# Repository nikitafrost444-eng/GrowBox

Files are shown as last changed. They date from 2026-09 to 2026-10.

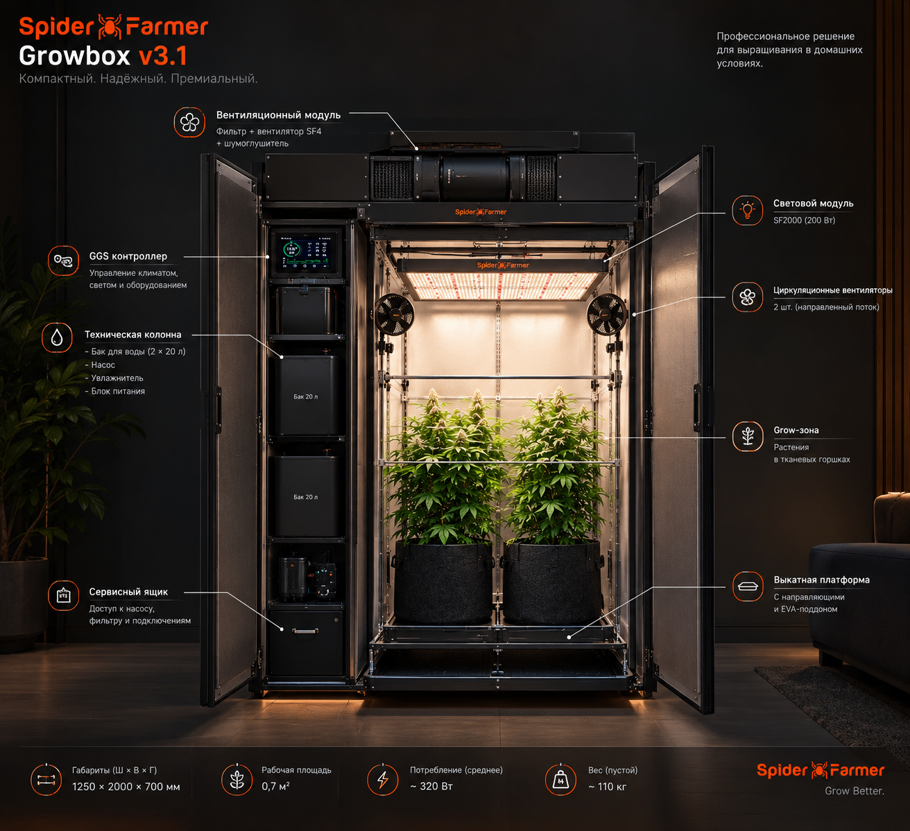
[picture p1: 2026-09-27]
images/concepts/ai_01_21-43.png

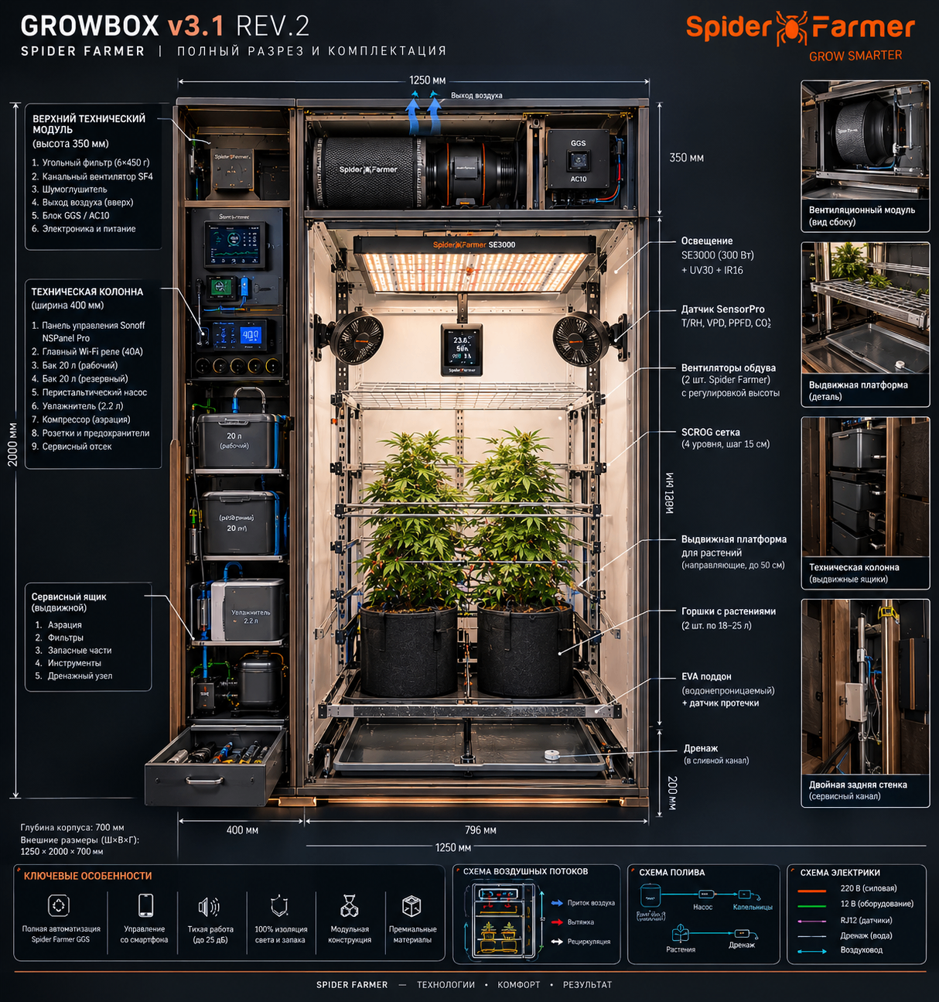
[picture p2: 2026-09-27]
images/concepts/ai_05_uuid.png

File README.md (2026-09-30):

# GrowBox — премиальный гроушкаф (проект v3.0 / v3.1 rev.2)

Тихий шкаф-гроубокс на 2 растения (SCROG) с полной автоматикой Spider Farmer GGS.
Принцип проекта: *выглядит как мебель · звучит как тишина · работает как швейцарские часы*.

**Габариты:** 1250 × 700 × 2000 мм · **Зона растений:** 796 × 620 мм (~0,49 м²) · **Свет:** SE3000 (300 Вт) на актуаторе · **Тишина:** вентиляция Ø100 с шумоглушителем и виброподвесами

---

## 🗂 Структура репозитория

| Папка | Содержимое |
|---|---|
| `docs/` | Документация: полное описание v1.0, спецификация v3.0 с картой раскроя, **v3.1 акустический техмодуль и шумоглушитель**, крепёжная карта, журналы сессий |
| `docs/drawings/` | Инженерные чертежи: разрез и план верхнего акустического модуля v3.1 |
| `models/` | 3D-модель: STEP (для КОМПАС-3D), STL, GLB + веб-просмотрщик, исходники (CadQuery) |
| `models/v3.1/` | **CAD v3.1 rev.2 (модульная архитектура A/B/C):** STEP по каждой детали + полная сборка, DXF раскроя, карта раскроя CSV, протокол проверок, исходник CadQuery |
| `models/renders/` | Цветные рендеры: общий вид, фасад, бок, разрез, сверху |
| `models/previews/` | Чертёжные SVG-превью |
| `pdf/` | Издательские PDF: концепция v1.0, описание v2.0, сборки v3.0 и v3.1 rev.2, **v3.1 rev.3 — полное описание и инструкция по сборке** |
| `images/concepts/` | AI-концепты внешнего вида |
| `images/equipment/` | Фото оборудования (SE3000, AC10, вентиляция, датчики и т.д.) |
| `sources/chats/` | Исходные обсуждения (Qwen, Алиса, ChatGPT) — стратегия, железо, модули |
| `sources/pdf-build/` | Вёрстка итогового PDF (HTML-страницы) и QA-скриншоты |

## 📄 С чего начать

1. **Спецификация и размеры** → [`docs/growbox_v3_spec.md`](docs/growbox_v3_spec.md) — канон v3.0: габариты, зонирование, электрика (2× AC10, 20 каналов), воздушный тракт, карта раскроя ЛДСП.
2. **Полное описание проекта** → [`docs/proekt_v1.0.txt`](docs/proekt_v1.0.txt) — исследование сообществ, акустика, вентиляция, автополив, спецификация Spider Farmer GGS.
3. **3D-модель** → `models/growbox_v3.step` — открыть в КОМПАС-3D (Файл → Открыть/Импорт), 76 именованных деталей; либо `models/viewer.html` + `models/growbox_v3.glb` в браузере.
4. **Итоговый PDF** → `pdf/growbox_v31_rev2.pdf`.
5. **v3.1 (в работе)** → [`docs/growbox_v3.1_acoustic-tech-module.md`](docs/growbox_v3.1_acoustic-tech-module.md) — верхний акустический техмодуль; [`docs/growbox_v3.1_silencer.md`](docs/growbox_v3.1_silencer.md) — самодельный двухкамерный шумоглушитель; [`docs/growbox_v3.1_fasteners.md`](docs/growbox_v3.1_fasteners.md) — крепёжная карта (узлы, крепёж, ссылки). Чертежи в `docs/drawings/`.
6. **CAD v3.1 rev.2 (модули A/B/C)** → [`models/v3.1/`](models/v3.1/) — 85 деталей, полная сборка STEP, DXF раскроя; импорт в КОМПАС-3D — по [`docs/kompas_import_v3.1.md`](docs/kompas_import_v3.1.md).
7. **📄 Главный документ rev.3** → [`pdf/growbox_v31_rev3.pdf`](pdf/growbox_v31_rev3.pdf) — полное описание, архитектура, инструкция по сборке и обслуживанию, чек-листы (12 страниц, цветные рендеры).

## 💻 Локальная сборка на своём ПК (Windows)

Чтобы не скачивать готовые файлы, а пересобирать модель под свои размеры:

1. Установи [Python 3.12](https://python.org/downloads/) — **с галочкой «Add python.exe to PATH»**
2. Склонируй репозиторий (или скачай ZIP: кнопка `Code → Download ZIP`)
3. В папке проекта запусти `setup.ps1` (правой кнопкой → Run with PowerShell) — поставит CadQuery
4. Запусти `build.bat` — модель пересоберётся, файлы обновятся в `models/v3.1/`

Чтобы поменять размеры: открой `models/v3.1/build_v31_modular.py`, блок параметров `P = dict(...)`
в начале (ширины модулей, толщины ЛДСП, габариты оборудования) → сохрани → `build.bat`.
Протокол проверок габаритов — `models/v3.1/reports/fit_check.txt`.

## 🔧 Ключевые решения v3.0

- **Свет:** SE3000 (603×585×71, PPF 856) — встаёт в зону с зазорами 96 мм по бокам; SE4500 снят (не влезает). Дополнительно UV30/IR16, зелёная подсветка 520–540 нм, актуатор подъёма 12 В (ход 300 мм).
- **Вентиляция:** лабиринт-приток → угольный фильтр SF 4" → вентилятор SF 4" (виброподвесы) → шумоглушитель → решётка 400×300 в комнату. Рабочие 80–135 м³/ч при объёме зоны 0,97 м³, разрежение обязательно.
- **Автоматика:** GGS Controller + 2× AC10 (20 розеток), ESP32, автодозатор A/B/микро + pH-модуль, перистальтика, компрессор аэрации, ИБП 600 ВА, Wi-Fi камера, датчик протечки, Soil Sensor Pro.
- **Корпус:** ЛДСП 18 мм, мокрая зона — фанера 18 + моющееся покрытие; раскладка по ширине 18+400+18+796+18 = 1250 мм. Раскрой укладывается в 2 листа 2800×2070.

## 🛠 Пересборка модели

Модель параметрическая (CadQuery):
```bash
python models/build_growbox_v3.py     # сборка STEP/STL/GLB
python models/render_matplotlib.py    # цветные рендеры
```

## 📌 Примечания

- `docs/opisanie_v2.0_broken-encoding.txt` — историческая выгрузка PDF v2.0 с битой кодировкой кириллицы (сохранена как есть; рабочая версия — `docs/proekt_v1.0.txt` и спецификация v3.0).
- `docs/session-notes_2026-09-27.md` — журнал принятых решений и технические заметки сессии проектирования.
- Открытые вопросы: летний сценарий (сплит в спальне?), конкретная модель Wi-Fi камеры.

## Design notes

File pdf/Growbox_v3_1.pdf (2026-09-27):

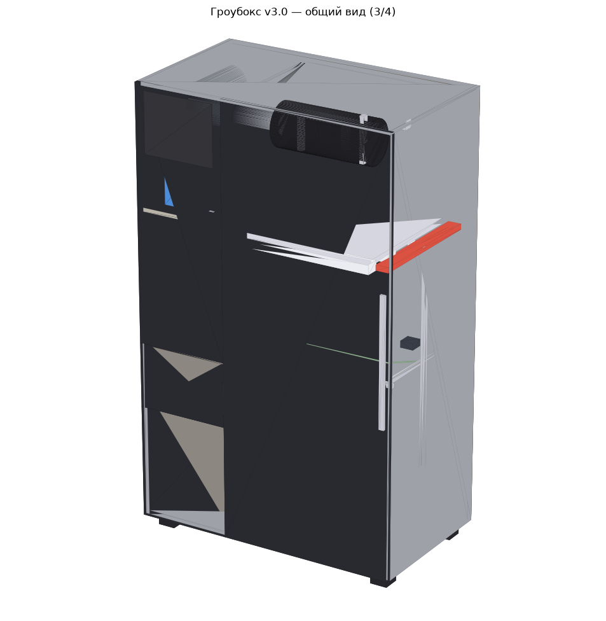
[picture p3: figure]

GROWBOX v3.1 • Spider Farmer centered concept | 1

# GROWBOX v3.1

## Spider Farmer centered • концепт инженерной ревизии

Цель версии: сохранить сильную механику v3.0, но сделать GGS единым центром климатической автоматизации, сократить самописную автоматику и повысить сервисопригодность, тишину и безопасность.

Ключевая идея: Spider Farmer управляет средой; корпус, разводка и аварийная защита проектируются независимо.

Документ подготовлен 27.09.2026. Это проектная ревизия, а не инструкция по сборке электроустановки. Перед изготовлением необходимо отдельно проверить актуальные модели, совместимость разъёмов GGS/RJ12 и требования местных электрических норм.

# 1. Что меняется в v3.1

v3.0 уже имеет хорошую базу: 1250×700×2000 мм, отдельную техколонну, влажную зону, SE3000, SF4, два почвенных датчика, резервный бак и полноценную сервисную панель. Главная проблема — слишком много параллельных систем управления.

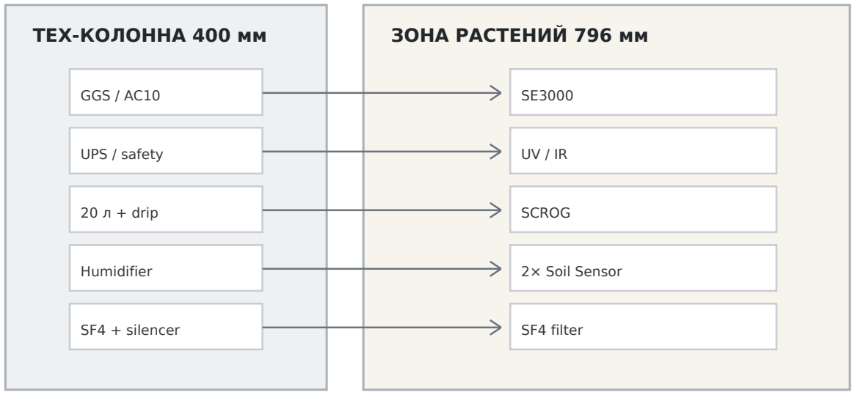
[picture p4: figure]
ТЕХ-КОЛОННА 400 мм; ЗОНА РАСТЕНИЙ 796 мм; GGS / AC10; UPS / safety; 20 л + drip; Humidifier; SF4 + silencer; SCROG; 2× Soil Sensor; SF4 filter

v3.1: GGS — главный мозг; механика и safety — независимые слои

## Решение v3.1

Узел | v3.0 | v3.1
Мозг | GGS + ESP32 | GGS как основной контроллер
Полив | собственная перистальтика + ESP32 | Spider Farmer Smart Drip / Soil Sensor
Свет | SE3000 + актуатор | SE3000, фиксированная механика, GGS/APP
Вентиляция | SF4 + AC10 | SF4 + GGS, плавное управление
pH / дозирование | самописный контур | отдельный сервисный контур
Safety | реле + ESP32 | независимый аварийный слой + leak shutdown

# 2. Корпус и компоновка

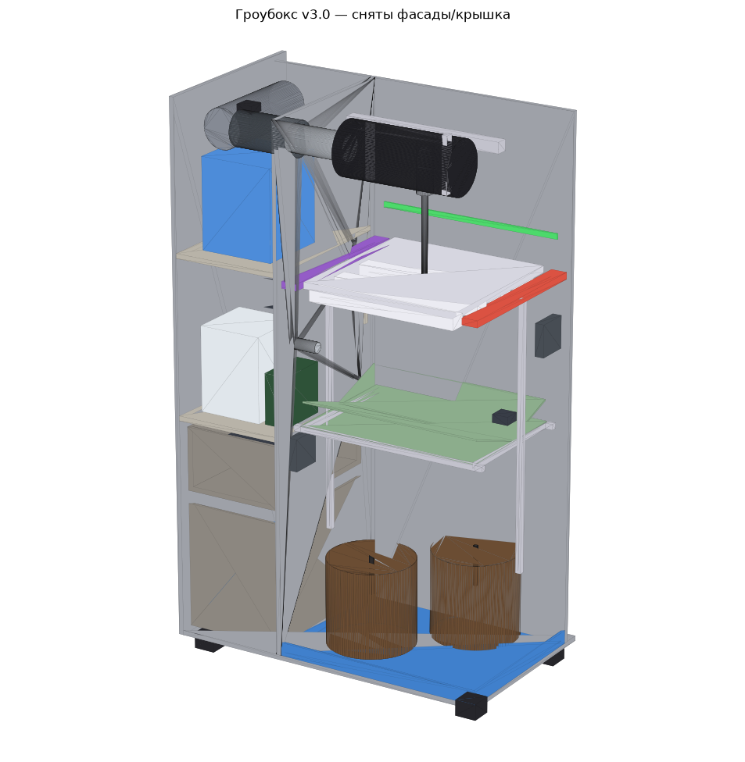
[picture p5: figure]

Канон v3.0: 1250 × 700 × 2000 мм; техколонна 400 мм; зона растений 796 × 620 × 1964 мм; задний кабельный колодец 58 мм.

Рекомендация v3.1: не фиксировать изготовление до финальной проверки BBox STEP. В исходной проектной документации отдельно отмечено расхождение между каноном и фактической габаритной геометрией модели. Для сервисной части предпочтителен увеличенный кабельный объём 80–100 мм, если помещение позволяет.

## Компоновка техколонны

Высота | Модуль v3.1 | Комментарий
0–520 | Рабочий бак 20 л | поддон + датчик протечки
520–820 | Полив / насос | съёмный сервисный ящик

820–1080 | Увлажнение / сервис | не ставить аэрозоль рядом с электроникой
1080–1420 | GGS / AC10 / БП | съёмная DIN-панель
1420–1778 | Резервный бак 20 л | механическая защита от перелива
1778–1982 | SF4 + шумоглушение | мягкий подвес

# 3. Свет — SE3000 как база

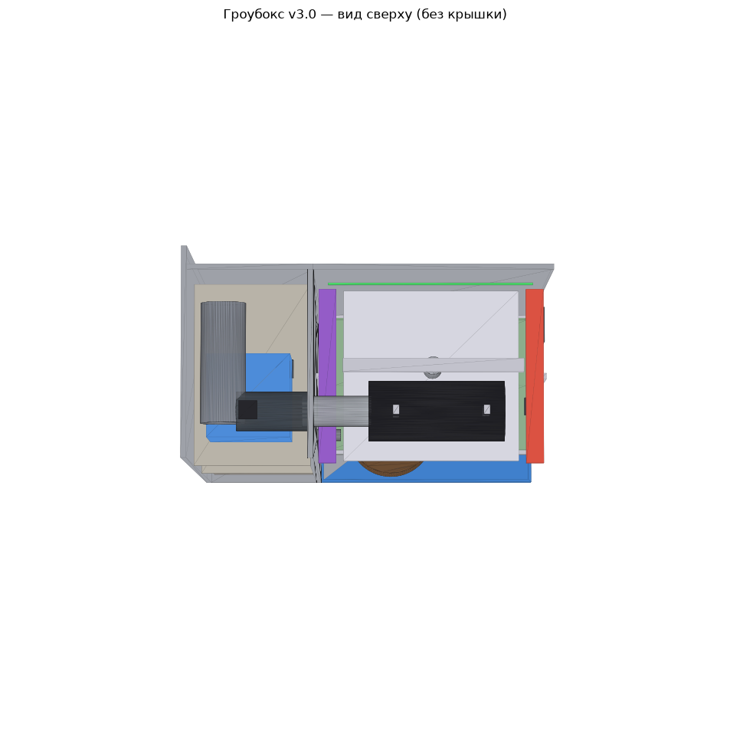
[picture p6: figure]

Актуальная страница Spider Farmer для 2026 SE3000 указывает 300 Вт, PPF 856 µmol/s, PPE 2.85 µmol/J, размеры около 603×585×71 мм и максимальное покрытие 3×3 ft. Новая версия использует Bridgelux; управление заявлено через Bluetooth/Wi‑Fi приложение и 0–10V. cite?

Для зоны 796×620 мм SE3000 подходит по геометрии и по площади. В v3.1 я бы убрал моторизированный подъём светильника: фиксированная механика + диммирование дают меньше движущихся деталей, меньше кабельных проблем и меньше точек отказа.

UV30 / IR16: оставить как отдельные вспомогательные каналы, но использовать их по расписанию, без сложной самописной логики.

Источник спецификаций: urlофициальная страница Spider Farmer SE3000https://www.spider-farmer.com/products/spider-farmer-upgraded-se3000-full-spectrum-led-grow-light/

# 4. Вентиляция и шум

Приток | Зона роста | Фильтр | SF4 | Шумоглушитель

Разрежение внутри зоны • фильтр строго ДО вентилятора • большой тихий выход

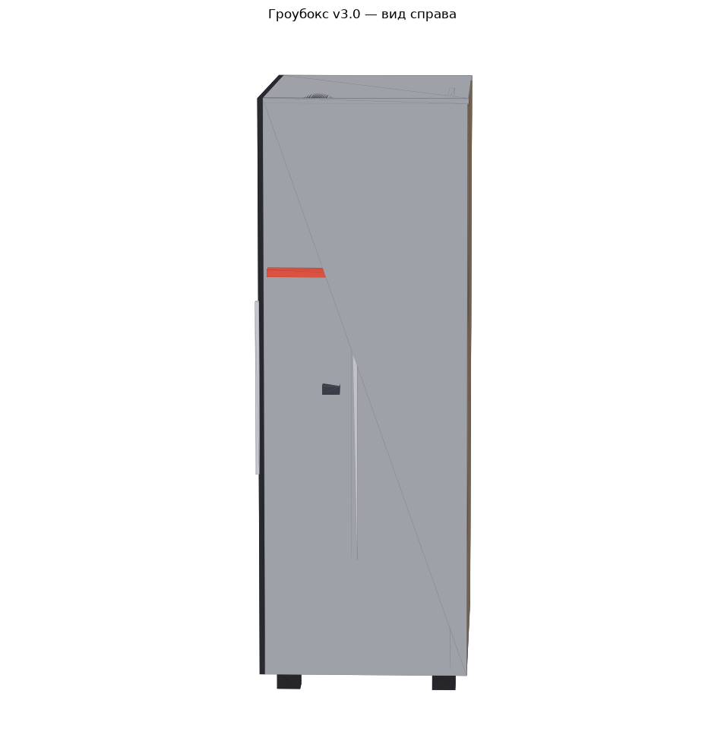
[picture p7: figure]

Схема v3.1: приток → зона растений → угольный фильтр → SF4 → шумоглушитель → большой выходной пленум. Фильтр остаётся до вентилятора, внутри шкафа поддерживается лёгкое разрежение.

Почему оставить SF4: текущая документация уже оптимизирована под компактный Ø100 тракт, а официальный Spider Farmer прямо указывает 4-inch fan как рекомендуемый для SE3000. Для этой камеры важнее хороший фильтр, плавная скорость и отсутствие резких сужений, чем максимальная производительность.

Шумоизоляция: вентилятор на виброразвязке; минимум 1–2 мягких участка; длинный тихий участок после вентилятора; выходной пленум с большой площадью решётки.

# 5. GGS — единый центр управления

Управляемые нагрузки

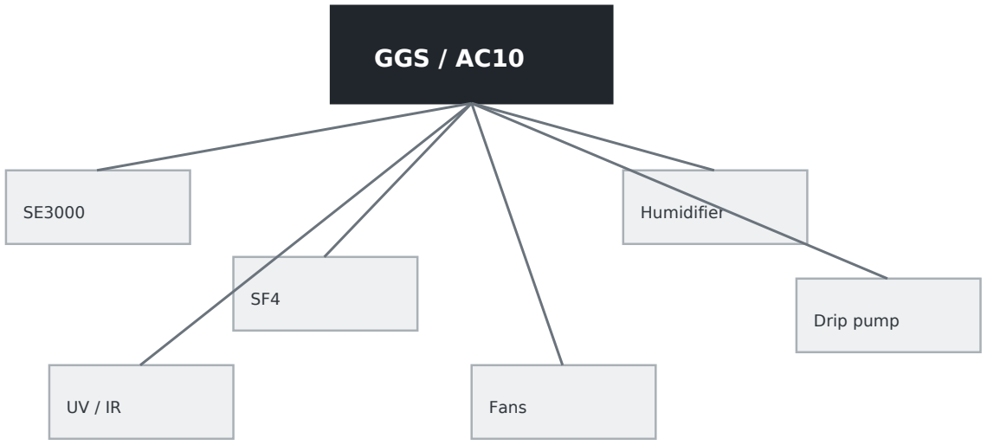
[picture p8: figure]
GGS / AC10; Humidifier; Drip pump; Fans

Spider Farmer сейчас предлагает связку GGS-контроллера с SE3000, 4-inch inline fan и климатическими датчиками; в официальных комплектах используются RJ12-соединения и управление через приложение. urlОфициальный комплект Spider Farmer с SE3000 + 4-inch fan + GGShttps://www.spider-farmer.com/products/spider-farmer-se3000-300w-led-grow-light-2x2x5%E2%80%B2-indoor-grow-tent-combo/

v3.1 принципиально меняет философию: ESP32 не управляет обычным режимом. Он либо удаляется, либо остаётся независимым монитором/аварийным слоем. Это снижает количество программных зависимостей и делает систему понятнее для обслуживания.

## Распределение каналов

Канал | Нагрузка | Логика
1 | SE3000 | расписание + диммирование
2 | SF4 | температура / RH / минимум ночью
3 | обдув | постоянно или по климату
4 | увлажнитель | по RH/VPD
5 | drip pump | Soil Sensor / расписание
6 | UV/IR | отдельное расписание
7+ | резерв | обогрев / сервис / будущее

# 6. Полив, датчики и вода

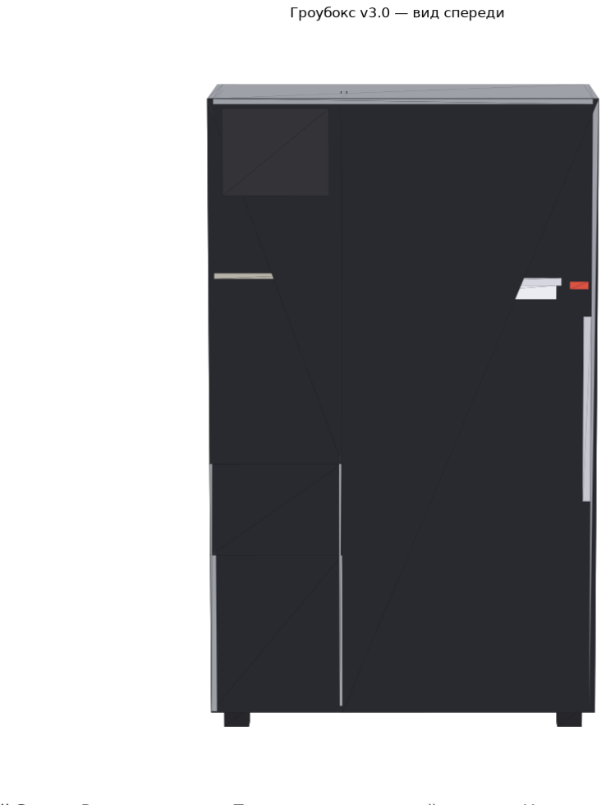
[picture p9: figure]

Два Soil Sensor Pro — оставить. По одному на каждый горшок. Не усреднять их показания: каждое растение получает собственную обратную связь.

Для v3.1 предпочтителен Spider Farmer Smart Drip/совместимый GGS-контур вместо самописной перистальтики, если конкретная версия системы доступна в твоём регионе и подтверждена совместимостью с выбранным AC10. Это наиболее прямой путь к цели «Spider Farmer ecosystem».

pH/EC: не смешивать с основной климатической логикой. Если нужен полностью автоматический pH dosing, это отдельный специализированный контур; GGS не следует превращать в самописный химический контроллер.

## Safety water layer

Событие | Немедленное действие
Протечка | насос OFF + увлажнитель OFF
Переполнение | подача OFF
Перегрев | SF4 → высокий режим

Потеря связи GGS | безопасный последний режим + независимый watchdog

# 7. Предварительная спецификация v3.1

Категория | Решение | Статус
Свет | Spider Farmer SE3000 300W (2026) | Оставить
UV/IR | Spider Farmer UV/IR bars | Оставить
Контроллер | Spider Farmer GGS | Главный мозг
Питание | AC10 / совместимый GGS power control | Уточнить финальную ёмкость каналов
Датчик климата | GGS Sensor / SensorPro | Оставить
Почва | 2× Soil Sensor Pro | Оставить
Вентиляция | Spider Farmer 4-inch inline fan | Оставить
Фильтр | Spider Farmer 4-inch carbon filter | Оставить
Обдув | Spider Farmer clip fan | Оставить
Увлажнение | Spider Farmer 5 L class humidifier | Оставить
Полив | Spider Farmer Smart Drip / GGS-compatible | Предпочтительно
pH/EC | отдельный сервисный контур | Опционально
ESP32 | монитор / safety only | Убрать из normal control
Актуатор света | моторизированный подъём | Убрать
Протечка | независимый hard shutdown | Добавить

# 8. Что проверить перед переходом к CAD

v3.1

① Зафиксировать внешний габарит и устранить расхождение STEP/BBox. ② Подтвердить конкретную ревизию AC10/GGS и количество доступных каналов. ③ Подтвердить совместимость выбранного SF4 с GGS/RJ12. ④ Проверить реальную геометрию фильтра и SF4 в верхнем отсеке. ⑤ Определить финальную схему полива и дренажа. ⑥ Разнести силовую и слаботочную трассы. ⑦ Сделать отдельную проверку теплового режима и аварийных сценариев.

Официальные источники: urlSpider Farmer — SE Serieshttps://www.spider-farmer.com/collections/led-grow-light/se-series-led-grow-light/ • urlSpider Farmer — GGS / комплектыhttps://www.spider-farmer.com/shop/ • urlSpider Farmer — центр руководствhttps://www.spider-farmer.com/user-manual-download-center/

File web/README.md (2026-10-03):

# Web · интерактивная 3D-модель GrowBox v3.1

Каноническая веб-страница с 3D-моделью шкафа. Геометрия **не нарисована на глаз** —
она сгенерирована из параметрической сборки `models/v3.1/build_v31_modular.py`
(те же 85 деталей, те же размеры, зазоры и петли).

## Файлы

| Файл | Что это |
|---|---|
| `index.html` | Основная страница: полный 3D, двери/ящики/газлифты, разрез, выбор деталей |
| `viewer_mobile.html` | Компактный просмотрщик под телефон (та же геометрия) |
| `model_parts.js` | Данные модели: 85 деталей (bbox, цвет, тип) из CAD |
| `vendor/three.min.js` | Three.js r128 (UMD, работает офлайн и с `file://`) |

## Как открыть

Просто открой `index.html` в браузере (двойной клик). Интернет не нужен —
библиотека и данные лежат рядом со страницей.

## Что можно делать

- **Вращать** — ЛКМ / пальцем, **зум** — колесо / щипок, **сдвиг** — Shift+ЛКМ
- **Открыть двери** — три створки-сэндвича вращаются вокруг реальных петель:
  дверь B — левый край (x=0), створка C1 — x=437 мм, створка C2 — правый край (x=1250)
- **Выдвинуть ящики** — бак, сервисный ящик, секрет-бокс (ход 450 мм)
- **Поднять фасады** — модули A и B на газлифтах, петля по верхней кромке (z=1700 / 2000)
- **Разрез** — корпус и фасады полупрозрачные, видно начинку
- **Свет SE3000** — подсветка камеры роста
- **Клик по детали** — название, модуль, габариты и описание

## Система координат

Данные в `model_parts.js` — в миллиметрах, в координатах CAD:
`X` — ширина 0…1250, `Y` — глубина 0…700 (0 — плоскость фасада), `Z` — высота −60…2000.
Просмотрщик пересчитывает их в метры и сдвигает центр в начало координат.

## Как обновить геометрию

1. Поменяй параметры в `models/v3.1/build_v31_modular.py` (блок `P = dict(...)`)
2. Пересобери модель (`build.bat` / `python build_v31_modular.py`)
3. Сгенерируй `model_parts.js` заново из сборки (та же функция экспорта bbox)
4. Обнови страницу — все размеры подтянутся автоматически

## Проверено

- Пропорции 1250×700×2000 (ширина < высота), модули A/B/C на своих местах
- Двери открываются наружу вокруг своих петель, ящики выезжают наружу, фасады поднимаются
- Работает из `file://` без интернета (three.js UMD подключён локально)

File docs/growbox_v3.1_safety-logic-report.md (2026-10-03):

# Прогон safety-логики — гроубокс v3.1 rev.3

**Статус:** ✅ **чек-лист ⑧ закрыт** (тепловой расчёт + прогон safety-логики).
**Дата:** 04.10.2026
**Инструмент:** [`safety_logic_sim.py`](safety_logic_sim.py) → протокол [`models/v3.1/reports/safety_logic.txt`](../models/v3.1/reports/safety_logic.txt)
**Пара к этому:** [`airflow_thermal_calc.py`](airflow_thermal_calc.py) (тепло, тракт, шум) и [`growbox_v3.1_electrical-safety.md`](growbox_v3.1_electrical-safety.md) (схема и защиты).

---

## 1. Что проверялось и чем

Тепловой расчёт отвечает на вопрос «сколько градусов». Прогон safety-логики
отвечает на другой вопрос: **при любом исходе аварии система не остаётся
в опасном состоянии**. Для этого взята дискретная модель управления:

```
датчики  ──►  правила (R1..R9)  ──►  исполнители  ──►  инварианты (H1..H8)
   t_cam, t_din, тахо вентилятора,        ГР.1 свет        свойства, которые
   датчик протечки, RCD3, РКН,            ГР.2 вентиляция  обязаны выполняться
   сеть 220 В, кнопка СТОП                ГР.3 вода        ВСЕГДА
                                            ГР.5 обогрев
```

Правила применяются до неподвижной точки (могут дополнять друг друга:
например, «протечка → RCD3 → обесточить ГР.3» — это два шага).
После сходимости проверяются инварианты.

## 2. Инварианты безопасности

| ID | Требование | Какой риск закрывает |
|---|---|---|
| **H1** | свет не горит без работающей вентиляции | терморазгон камеры за минуты (300 Вт при нулевом воздухообмене) |
| **H2** | при протечке вода перекрыта (клапан закрыт, помпа OFF) | затопление комнаты |
| **H3** | при сработавшем RCD3 группа воды обесточена | поражение током через воду |
| **H4** | нет «блуждающего» открытого клапана без питания | неконтролируемая подача воды |
| **H5** | обогрев ГР.5 не работает при t_din ≥ 55 °C | пожар/деградация щитка |
| **H6** | свет гаснет при t_cam ≥ 33 °C | перегрев растений и драйвера |
| **H7** | кнопка СТОП обесточивает свет и воду | ручной рубильник работает как заявлено |
| **H8** | пропала сеть → свет погашен аппаратно | свет остался, вентиляция сдохла → терморазгон |

## 3. Сценарии (13 шт.)

| Сценарий | Вердикт |
|---|---|
| Норма | PASS |
| Пропала сеть (свет включён) | PASS |
| Пропала сеть (тёмная фаза) | PASS |
| Протечка | PASS |
| Протечка + пропала сеть | PASS |
| Отказ вентилятора | PASS |
| Перегрев камеры (34,5 °C) | PASS |
| Перегрев DIN-панели (56 °C) | PASS |
| Отказ датчика температуры | PASS |
| Засорён фильтр (140 Па) | PASS |
| Аварийная кнопка СТОП | PASS |
| Ложное срабатывание RCD3 | PASS |
| ГР.2 обесточена, свет остался | PASS |

**Нарушений инвариантов: 0.** Правила R1..R9 самосогласованы: каждая авария
доводит систему до безопасного состояния, а не оставляет её «висеть».

Ключевые цепочки, которые подтвердились:

- **пропала сеть** → РКН гасит ГР.1 → ГР.3 обесточена, клапан NC закрыт →
  на ИБП остаются вентиляция и электроника (~1,0–1,2 ч автономности);
- **протечка** → RCD3 / датчик → ГР.3 OFF, клапан закрыт, помпа OFF →
  свет и вентиляция продолжают работать (шкаф «дышит», не гаснет целиком);
- **отказ вентилятора** → свет OFF + тревога (главная защита H1);
- **отказ датчика температуры** → консервативный режим: свет OFF, вентиляция 100 %.

## 4. Найденные расхождения в документации (к правке)

Прогон формализовал логику, и при сверке с текстом
[`growbox_v3.1_electrical-safety.md`](growbox_v3.1_electrical-safety.md)
всплыло **6 расхождений**. Все печатаются в протоколе при каждом запуске скрипта.

| # | Где | Суть | Что сделать |
|---|---|---|---|
| **FIND-01** | §5 ИБП | «при пропаже сети сохраняем клапан воды ON», но клапан в ГР.3, а ГР.3 не на ИБП | убрать строку; зафиксировать: ГР.3 обесточивается, клапан NC закрывается — это и есть fail-safe |
| **FIND-02** | §8 СТОП | «СТОП разрывает ГР.1/2/3/5, но не клапан воды» — но клапан питается из ГР.3 | убрать «и не клапан воды»: СТОП перекрывает воду (вариант безопаснее) |
| **FIND-03** | §4 Мокрая зона | отсечка воды описана только через RCD3, а протечка без касания токоведущих частей RCD3 не вызовёт | добавить правило «датчик протечки → закрыть клапан + помпа OFF» независимо от RCD3 |
| **FIND-04** | §7 Термоконтроль | не описано поведение при отказе датчика температуры | добавить: отказ датчика → свет OFF, вентиляция 100 %, тревога |
| **FIND-05** | §5 таблица ИБП | строка «свет + вентиляция + электроника 401 Вт» подразумевает свет на ИБП, которого там нет | переименовать в гипотетическую или убрать; реальный расчёт — 100 Вт → ~1,0–1,2 ч |
| **FIND-06** | §5 | требование «свет гаснет аппаратно через РКН» есть, а зеркального «отказ вентилятора → свет OFF аппаратно» нет | зафиксировать: тахосигнал вентилятора → реле в разрыве ГР.1 (закрывает H1) |

> Все шесть — это правки текста документа, а не переустройство железа.
> Железо в проекте спроектировано правильно (клапан NC, 5 групп, УЗО типа A),
> противоречия — в формулировках.

## 5. Итог по чек-листу ⑧

| Подпункт | Статус |
|---|---|
| Тепловой расчёт (перегрев, необходимый расход, летний сценарий) | ✅ `airflow_thermal_calc.py` |
| Расчёт сопротивления тракта и рабочая точка вентилятора | ✅ там же |
| Оценка шума тракта | ✅ там же |
| **Прогон safety-логики (инварианты + аварийные сценарии)** | ✅ `safety_logic_sim.py` |
| Правка документации по FIND-01…06 | ⬜ открыто (нужны правки в `electrical-safety.md`) |

**Остальные открытые пункты проекта не тронуты:**
⑤ ревизии GGS/AC10/SF4 — нужны обмеры реального оборудования (от пользователя).

## 6. Как перепроверить

```bash
python3 docs/safety_logic_sim.py                       # прогон, exit 0 = всё ок
python3 docs/safety_logic_sim.py > models/v3.1/reports/safety_logic.txt   # обновить протокол
python3 docs/airflow_thermal_calc.py                   # тепловая половина ⑧
```

При изменении правил (новая группа, новый датчик) — сначала добавить сценарий,
потом инвариант, потом править железо. Порядок такой, чтобы правило нельзя
было «забыть» при перепроектировании.

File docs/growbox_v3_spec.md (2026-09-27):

# Гроубокс v3.0 — сводная спецификация к 3D-модели

**Статус:** размеры согласованы, модель `growbox_v3.step` собрана по этому документу.
**Дата:** 27.09.2026. Приоритетные решения: свет **SE3000**, вентилятор **SF 4"**, полный набор автоматики.

---

## 1. Габариты и зонирование (канон версии v3.0)

| Параметр | Значение | Комментарий |
|---|---|---|
| Корпус (Ш × Г × В) | **1250 × 700 × 2000 мм** | без фасадов; с фасадами глубина 718 мм |
| Тех-колонна (сухая), внутр. | 400 × 620 × 1964 | слева |
| Зона растений (влажная), внутр. | **796 × 620 × 1964** | справа, ~0,49 м² пола |
| Задний кабельный колодец | 58 мм (сзади за стенками зон) | закрыт оргалитом 4 мм |
| Перегородка / стенки | ЛДСП 18 мм | мокрая зона — фанера 18 + моющееся покрытие |
| Опоры | 4 × демпферные, 60 мм | пробка/каучук, виброразвязка с полом |

> **Раскладка по ширине (сходится точно):** 18 + 400 + 18 + 796 + 18 = 1250.
> В v2 «450 + 800 + 80» не сходилось с 1250 — здесь исправлено: колонна 400 мм
> (в неё свободно встаёт бак 280 мм с направляющими), зона растений 796 мм.

## 2. Почему SE3000 встаёт (проверено по спецификации SF)

- SE3000: **603 × 585 × 71 мм**, 300 Вт, PPE 2.85, PPF 856 µmol/s, покрытие до 90×90 см.
- В зоне 796 × 620: зазоры **96 мм по бокам, ~17 мм впереди/сзади** — светильник висит свободно,
  воздух омывает радиаторы со всех сторон.
- Размещение: по центру зоны (X = 834), высота в модели 1350–1421 мм, на штоке актуатора (ход 300 мм).
- UV30 и IR16 (60 см) — по бокам вдоль глубины, на той же высоте.
- SE4500 (115 × 37 см) в эти габариты **не влезает** — окончательно снят с рассмотрения.

## 3. Вертикальная раскладка тех-колонны (Z, мм)

| Диапазон | Модуль | Нагрузка |
|---|---|---|
| 0–520 | Ящик с рабочим баком 20 л | ~25 кг, Blum Tandem 500 + усиление |
| 520–820 | Ящик: перистальтика, компрессор, ИБП 600 ВА | ~15 кг |
| 820–1080 | Секрет-бокс: увлажнитель SF 5 л, дозатор удобрений, pH-модуль, Wi-Fi камера | — |
| 1080–1420 | DIN-панель: 2× AC10, GGS Controller, БП 12 В, DPDT, ESP32 | ~5 кг |
| 1420–1778 | Резервный бак 20 л на полке с рамой 30×30 + поплавковый клапан 3/4" | ~22 кг |
| 1778–1982 | Вент-модуль: SF 4" на виброподвесах, шумоглушитель, решётка 400×300 в комнату | ~7 кг |

## 4. Зона растений (Z, мм)

| Диапазон | Модуль |
|---|---|
| 18–68 | Коврик EVA с бортами 50 мм + датчик протечки |
| 68–388 | 2 горшка 15 л (Ø320), Soil Sensor Pro в каждом |
| 400–1400 | Направляющие SCROG на боковинах (ход), рамка V 700×500 на кронштейнах, борта 18° — канопа ~0,65 м² |
| 1351–1421 | SE3000 + UV30/IR16 (в модели — рабочее положение) |
| 1421–1710 | Шток актуатора 12 В (ход 300 мм, ручной аварийный сброс — быстросъём) |
| 1710–1902 | Корпус актуатора на траверсе 600 мм |
| 1775–1975 | Угольный фильтр SF 4" горизонтально (торец — к сервисной зоне) |
| 1520 | LED-полоса 520–540 нм (работа в тёмной фазе) |

## 5. Воздушный тракт (в модели показан схематично)

Приток: лабиринт внизу двери зоны растений → растения → фильтр SF 4" (под потолком зоны)
→ воздуховод Ø100 через сервисную перегородку → вентилятор SF 4" (виброподвесы, шумо-отсек)
→ шумоглушитель → пленум с решёткой 400×300 → комната.

- Расчёт: объём зоны 0,97 м³ → 80–135 м³/ч рабочих; SF 4" (до ~220 м³/ч) на 35–50% — запас есть.
- Разрежение обязательно: сечение притока > вытяжного; фильтр — строго до вентилятора.

## 6. Сервисная перегородка — отверстия (в модели прорезаны)

| Отверстие | Назначение |
|---|---|
| Ø100, Z=1875 | тракт фильтр → вентилятор |
| Ø40, Z=1150 | патрубок увлажнителя |
| 3× Ø25, Z=1330/1370/1410 | RJ12 датчики, слаботочка |
| Ø20, Z=900 | силовой ввод, шланги полива 4/6 мм |

Все вводы — с резиновыми гермовводами (PG-13.5 / PG21), ≥150 мм от пола.

## 7. Электрика — карта каналов (2× AC10, 20 розеток)

| Канал | Устройство | Режим |
|---|---|---|
| 1 | Свет SE3000 (драйвер) | расписание + автодиммер по PAR/DLI |
| 2 | Вентилятор SF 4" | триггеры T/RH, минимум ночью |
| 3 | БП обдува 12 В | постоянно / по датчикам |
| 4 | Увлажнитель SF 5 л | триггер VPD |
| 5 | Помпа перистальтики | по Soil Sensor / расписанию |
| 6 | Компрессор аэрации | таймер (15 мин/час) |
| 7 | Реле актуатора «ВВЕРХ» | импульсное |
| 8 | Реле актуатора «ВНИЗ» | импульсное |
| 9 | UV30 | последние 2–3 недели цветения |
| 10 | IR16 | рассвет/закат ±15 мин |
| 11–14 | Дозатор A/B/микро + pH-насос | по ESP32 + EC/pH |
| 15–20 | Резерв (обогрев, осушитель, сервис) | — |

Постоянная группа (вне AC10): камера Wi-Fi (ИК ночью выкл!), GGS Controller/БП, ИБП 600 ВА
(держит Controller + 2 канала AC10 + камеру ~20 Вт, 2–4 ч). Один силовой кабель наружу.

## 8. Ключевые решения v3.0 (что изменилось против v2)

1. **SE3000 вместо SE4500** — габаритный конфликт закрыт (см. п. 2).
2. **Вентилятор SF 4"** (Ø100 тракт вместо Ø150) — тише в рабочей точке, дешевле, компактнее
   в колонне 400 мм; глушение — изоляцией и шумоглушителем, как решено.
3. **Арифметика габаритов приведена в порядок**: колонна 400, зона 796, колодец 58 мм (было
   «80» — ужато, чтобы сохранить внешние 700 мм глубины; при необходимости корпус 720).
4. Полный набор автоматики сохранён: актуатор, дозатор, pH, ИБП, зелёная подсветка, камера.

## 9. Карта раскроя (корпус)

| № | Деталь | Размеры, мм (Д×В×Т) | Кол-во | Материал |
|---|---|---|---|---|
| 1 | Боковина левая | 700 × 2000 × 18 | 1 | ЛДСП 18 |
| 2 | Боковина правая | 700 × 2000 × 18 | 1 | ЛДСП 18 |
| 3 | Крышка | 1214 × 700 × 18 | 1 | ЛДСП 18 |
| 4 | Дно | 1214 × 700 × 18 | 1 | ЛДСП 18 |
| 5 | Перегородка сервисная | 620 × 1964 × 18 | 1 | ЛДСП 18 (прорези по схеме) |
| 6 | Задняя стенка тех-зоны | 418 × 1964 × 18 | 1 | Фанера 18 |
| 7 | Задняя стенка зоны роста | 796 × 1964 × 18 | 1 | Фанера 18 |
| 8 | Оргалит колодца | 1214 × 1964 × 4 | 1 | Оргалит 4 |
| 9 | Дверь зоны роста | 822 × 2000 × 18 | 1 | ЛДСП 18, петли Blum ×5 |
| 10 | Фасад тех-зоны верх | 428 × 1180 × 18 | 1 | ЛДСП 18 |
| 11 | Фасад ящика (помпа) | 428 × 300 × 18 | 1 | ЛДСП 18 |
| 12 | Фасад ящика (бак) | 428 × 520 × 18 | 1 | ЛДСП 18 |
| 13 | Полка секрет-бокса | 400 × 620 × 18 | 1 | ЛДСП 18 |
| 14 | Полка резервного бака | 400 × 620 × 18 | 1 | ЛДСП 18 + рама 30×30 |
| 15 | Панель электроники | 400 × 340 × 10 | 1 | Фанера 10, съёмная |
| 16 | Ящик бака (комплект) | 374 × 550 × 470 | 1 | ЛДСП 12 + Tandem 500 |
| 17 | Ящик насосов (комплект) | 374 × 550 × 240 | 1 | ЛДСП 12 + Tandem 500 |

Раскрой ориентировочно укладывается в 2 листа ЛДСП 2800×2070 + остатки на ящики.

## 10. Файлы модели

| Файл | Назначение |
|---|---|
| `growbox_v3.step` | **основной** — открыть в КОМПАС-3D (Файл → Открыть/Импорт), сборка с именами деталей |
| `growbox_v3.stl` | быстрый просмотр / 3D-печать макета |
| `growbox_v3.glb` | цветная модель для любого 3D-просмотрщика / веба |
| `viewer.html` | веб-просмотрщик GLB (открыть в браузере рядом с `growbox_v3.glb`) |
| `render_iso/front/side/cut/top.png` | цветные рендеры: общий вид, фасад, бок, разрез без фасадов, вид сверху |
| `preview_iso/front/side/top.svg` | чертёжные превью (тонкие линии, как в CAD) |
| `growbox_v3_spec.md` | этот документ |
| `build_growbox_v3.py` | исходник модели (CadQuery) — менять размеры и пересобирать |
| `render_matplotlib.py` | генератор цветных рендеров |

Все детали в сборке именованы (Боковина_левая, Перегородка_сервисная, SE3000_каркас и т.д.) —
в дереве КОМПАСа их можно выключать по одному, менять цвета и делать разрезы. Имена записаны
стандартными эскейпами STEP (\X2\) — кириллица отображается корректно.

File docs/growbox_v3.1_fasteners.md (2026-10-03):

# v3.1 rev.3 — крепёжная карта (модульная схема A/B/C)

**Статус:** пересобран под модульную архитектуру rev.2/rev.3 · 04.10.2026
**Геометрия-источник:** [`models/v3.1/build_v31_modular.py`](../models/v3.1/build_v31_modular.py) (85 деталей, 38 плоских)
**Связанные документы:** [акустический техмодуль](growbox_v3.1_acoustic-tech-module.md) · [шумоглушитель](growbox_v3.1_silencer.md) · [электрика и ЭБ](growbox_v3.1_electrical-safety.md) · [safety-логика](growbox_v3.1_safety-logic-report.md)

> **Что изменилось против прежней карты (28.09):** карта разбита по модулям
> A/B/C, а не «по узлам вообще»; уточнены петли (Blum Clip **×4 на дверь**,
> как в rev.3, а не ×5), ход выкатной платформы (**240 мм** по CAD-параметру
> `PLATFORM_TRAVEL`, а не 450), сэндвич дверей растёт **наружу** (габарит
> по глубине 741 мм), добавлены утопленный цоколь 55 мм, крышки баков,
> цветные гермовводы и органайзер двери B.

---

## 0. Модульная схема — за что отвечает каждый модуль

| Модуль | Габарит | Содержимое | Особенность крепления |
|---|---|---|---|
| **A** · верхний акустический | 1250 × 700 × 300 | фильтр SF4 → вентилятор SF4 → двухкамерный глушитель → пленум → решётка 400×300 | всё на **виброразвязке**; тракт Ø250 при внутренних 282 мм |
| **B** · тех-колонна | 400 × 600 × 1700 | ящик рабочего бака 20 л, сервисный ящик, секрет-бокс (увлажнитель), съёмная DIN-панель, полка резервного бака на раме 30×30 | мокрая зона + электрика; крепёж нержавейка A2 |
| **C** · камера роста | 796 × 600 × 1700 | EVA-поддон, выкатная платформа, 2 горшка 15 л, SCROG V-рамка (4 уровня), SE3000 + UV/IR на роликовых подвесах, SensorPro | всё над растениями — **крепёж под отказ** |
| **B+C** · общий корпус | 1250 × 700 × 1700 | боковины, дно, перекрытие, перегородка B-C, задние стенки, сервисный канал 80 мм | силовой контур; стяжки + шип-паз |

**Раскладка по ширине:** 18 (боковина) + 400 (B) + 18 (перегородка) + 796 (C) + 18 (боковина) = **1250**.
**По глубине:** 600 (зона) + 12 (фанера) + 80 (сервисный канал) + 8 (оргалит) = **700**; с дверями-сэндвич 41 мм → **741**.
**По высоте:** 1700 (B+C) + 300 (A) = **2000**.

---

## 1. Три контура крепления (принцип — без изменений)

| Контур | Что входит | Правило |
|---|---|---|
| **Силовой** | баки 20 л, фильтр, актуатор, DIN-панель, полки, платформа горшков, рама 30×30 | только к каркасу/стойкам 3030 или сквозной крепёж; никаких «саморезов в полку» |
| **Виброразвязанный** | SF4, глушитель, перистальтика, компрессор | площадка + виброопоры; жёсткой связи с корпусом нет |
| **Сервисный** | крышки, ревизии, DIN-панель, крышки баков, съёмные панели | быстросъёмное (барашки, quarter-turn, эксцентрики); если нужна отвёртка — туда не полезут |

**Правило «крепёж под отказ»:** всё, что висит над растениями (фильтр, SE3000,
шток актуатора), имеет **страховочный элемент** — вторую шпильку или трос-предохранитель.

---

## 2. Корпус B+C (силовой контур)

| Деталь (по `cutlist.csv`) | Кол-во | Крепёж |
|---|---|---|
| 01/02 Боковины B-C, ЛДСП 18 | 2 | стяжки межсекционные 4–6 на стык + шип-паз |
| 03 Дно B (418×700) и Дно C (796×700) | 2 | к боковинам через гайки-бочонки М5/М6 |
| 04 Полка-перекрытие B и C | 2 | то же; на ней сидит модуль A |
| 05 Перегородка B-C сервисная (18×600×1664) | 1 | **гермовводы PG-13.5/PG21** в перегородке, все ≥150 мм от пола |
| 06/07 Задние внутренние (фанера 12/18) | 2 | влагостойкая зона, покрытие моющееся |
| 08 Задняя наружная (оргалит 8) | 1 | между 06/07 и 08 — **сервисный канал 80 мм** |
| 09 Опоры демпферные 80×80×60 | 4 | каучук/пробка, гасят вибрацию в пол |
| 46 Цоколь передний (утоплен 42 мм) | 1 | разгружает пол: нагрузка идёт на ленту, не на цоколь |
| 47 LED цоколя 24 В | 1 | свет только внутрь, снаружи не видно |

**Сервисный канал:** 4 трассы разнесены и подписаны цветом — 🟡 жёлтый 220 В,
⚪ белый слаботочка, 🔵 синий вода, ⚫ серый воздух. Соединений в канале нет —
только прокладка; все стыки — в модуле B.

---

## 3. Модуль A — верхний акустический (виброразвязанный контур)

| Узел | Решение | Нагрузка на виброопору |
|---|---|---|
| **Фильтр SF4** (корпус Ø250×350) | хомутовая лента на 2 шпильках М6 + резиновые проставки; **отдельный подвес** | — (подвес) |
| **Вентилятор SF 4"** (Ø250×240) | площадка 20 мм + **4 виброопоры** каучук Shore A 40–60 | ~1,2 кг (×1,5 динамика) |
| **Шумоглушитель** (Ø250×330) | собственная полка + 4 виброопоры | ~5,5 кг |
| **Пленум выходной** (220×300×262) | на профиле 3030, крепёж через резину | — |
| **Решётка 400×300** | на фасаде A, саморезы + уплотнитель | — |
| Соединения тракта | гибкие вставки Ø100 с обеих сторон каждого виброузла; хомуты к профилю через резину | — |
| Ревизия глушителя | съёмная крышка на винтах М6 + прокладка (сервисный контур) | — |

**Габаритный узел:** тракт Ø250 в модуле высотой 300 мм — зазор 32 мм сверху/снизу.
Учесть выступ виброопор: проверить по фактическим ревизиям (чек-лист ⑤).

**Фасад A (15)** — сэндвич 41 мм (ЛДСП 18 + MLV 3 + минвата 20), **растёт наружу**.
Петля по верхней кромке (z = 2000), **газлифты ×2**. Петли: **Blum Clip ×4**.

---

## 4. Модуль B — тех-колонна (мокрая зона + электрика)

| Узел | Решение | Примечание |
|---|---|---|
| **29 Ящик бака** (374×550×470) | Blum Tandem 500, полное выдвижение, усиленное дно | бак 31 + крышка 62 |
| **31 Бак рабочий 20 л** (350×250×230) | на сквозных шпильках М6 с шайбами к днищу ящика | ~25 кг с водой |
| **62 Крышка бака** | сервисный контур, съёмная | + поплавок 3/4" |
| **30 Ящик сервисный** (374×550×240) | Tandem 500 | перистальтика, компрессор, расходники |
| **33 Полка секрет-бокса** (400×600×18) | гайки-бочонки М6 | увлажнитель 34 (300×220×300) |
| **35 DIN-панель съёмная** (400×340×10) | на барашках/быстросъёме, **в сухой зоне**, глубже 240 мм | GGS 36 + 2×AC10 37 + ИБП 38 |
| **39 Полка резервного бака** (400×600×18) | на раме 30×30 (40, ×4), шпильки | бак 41 + крышка 63 |
| **48 LED рабочая** модуля B | сервисная подсветка, свет внутрь | обслуживание без света роста |
| **60/61 Органайзер двери B** | 3 кармана 48 мм в зоне z1060–1360 | зона свободна от фасадов |

**Металл в мокрой зоне — нержавейка A2.** Отверстия с прокладками/герметиком,
точки крепления выше зоны залива. Соединений в мокрой зоне нет вообще
(требование [электрики](growbox_v3.1_electrical-safety.md), раздел 4).

**Фасады B (11–14):** ящик бака 500 мм, сервисный 280 мм, секрет-бокс 260 мм,
верхний на **газлифтах ×2** (петля по верхней кромке z = 1700). Щель 2–3 мм.

---

## 5. Модуль C — камера роста (крепёж под отказ)

| Узел | Решение | Страховка |
|---|---|---|
| **21 EVA-поддон** (750×590×60, борт 50) | вкладыш съёмный, слив в дренаж | датчик протечки на дне |
| **22 Платформа выкатная** (750×590×20) | **Blum Tandem 500**, полное выдвижение, **ход 240 мм** (`PLATFORM_TRAVEL`); нагрузка ~50 кг (2 горшка 15 л мокрые) → запас ≥1,5 = 75 кг | шпильки платформы к направляющим |
| **23 Горшки 15 л (Ø320×250)** | 2 шт. на платформе | — |
| **24 SCROG V-рамка** (700×500×20, 4 уровня, шаг 180, от z=350) | SBR16: 2 вертикальных рельса + каретки с фиксатором; рама съёмная | ограничители хода SBR16-FR сверху/снизу |
| **25 SE3000** (603×585×71, 5,4 кг) | линейный актуатор 12 В, 300 мм, 800N на траверсе профиля; ход 300 мм; зазоры по X ±96 мм, **по Y ±7,5 мм** | 2× трос-предохранитель + верхний стопор хода |
| **26 UV30/IR16 бары** (600×60×40) | на отдельных подвесах (27, роликовые ×4) | трещотки-растяжки |
| **28 SensorPro** | кронштейн на стойку, кабель в сервисный канал | — |
| **Обдув** | кронштейны на профиль + резиновые проставки, перестановка по стойкам | — |

⚠️ **Узкое место:** SE3000 по Y — зазор ±7,5 мм. До закупки проверить по
фактической ревизии светильника (чек-лист ⑤).

---

## 6. Двери и фасады

| Позиция | Решение |
|---|---|
| Двери | три створки против провисания: **B 434 мм + C1 405 + C2 405**, зазоры 3 мм |
| Сэндвич дверей | ЛДСП 18 + MLV 3 + минвата 20 = **41 мм**, растёт **наружу** (интерьер 600 мм не трогаем — иначе SE3000 не входит) |
| Петли | **Blum Clip ×4 на дверь** (12 шт. на три створки), с доводчиком — тихое закрывание часть ТЗ |
| Уплотнение | EPDM по периметру + лабиринт в торце (слабое акустическое место) |
| Замок | магнитный push-to-open или электронный + шпингалеты с фиксатором; отверстие закладывать на раскрое |
| Фасады ящиков | эксцентрики/мебельные подвесы, щель 2–3 мм |

---

## 7. Позиции крепежа к закупке

| Позиция | Что искать | Где |
|---|---|---|
| Актуатор света | Линейный привод 12 В, ход 300 мм, 800N, с кронштейнами | [Ozon](https://www.ozon.ru/product/lineynyy-privod-aktuator-12-v-dlina-hoda-300-mm-do-80-kg-800n-12-mm-s-s-montazhnymi-1503777422/) |
| Салазки SCROG | Комплект SBR16: 2 рельса 1200 + 4 каретки с фиксатором | [Ozon](https://www.ozon.ru/product/komplekt-lineynyh-napravlyayushchih-sbr16-1200mm-2-relsa-4-karetki-s-fiksatorom-2-fiksiruyushchih-4799162530/) |
| Каретки/стопоры | SBR16LUU, ограничители SBR16-FR | [rsi-llc.ru](https://www.rsi-llc.ru/catalog/173/1182/) · [стопор](https://www.rsi-llc.ru/catalog/173/2107/) |
| Телескопы | Blum Tandem 500 / Hettich Quadro, полное выдвижение, 500 мм, ≥40 кг/пару — **3 пары** (ящик бака, сервисный, платформа C) | [Лемана ПРО](https://saratov.lemanapro.ru/catalogue/napravlyayushchie-dlya-yashchikov/450mm/) |
| Петли | **Blum Clip ×12** (4 на дверь × 3 створки) + доводчики | мебельная фурнитура |
| Газлифты | ×4 (фасад A + верхний фасад B), по 2 на фасад | мебельная фурнитура |
| Подвесы/страховка | трещотки-растяжки для фитоламп, тросы-предохранители | [Ozon, подвесы](https://www.ozon.ru/category/podvesy-dlya-fitolamp/) |
| Каркас | профиль 3030 паз 8 + Т-гайки М6 | [rsi-llc.ru](https://www.rsi-llc.ru/) (раздел «Конструкционный профиль») |
| Быстрозажим | рычажные гайки под паз 8 (M6) | [AliExpress](https://www.aliexpress.com/w/wholesale-m6-lever-nut-3030.html) |
| Гермовводы | PG-13.5 / PG21 с уплотнителями, **цветные** (🟡 220 В / ⚪ слаботочка / 🔵 вода / ⚫ воздух) | электротовары |

---

## 8. Правила сборки (чек-лист)

1. Виброузлы не касаются корпуса — проверить зазоры после затяжки (модуль A).
2. Все страховочные тросы натянуты, но не несут нагрузки в норме.
3. Стопоры хода SBR16 и актуатора выставлены до первого включения.
4. Швы мокрой зоны промазаны герметиком; отверстия крепежа — с прокладками.
5. Маркировка: каждый крепёж и разъём подписан; трассы в сервисном канале — по цветам.
6. Ревизионные крышки и DIN-панель открываются без инструмента (сервисный контур).
7. Сэндвич дверей собран до установки петель: MLV и минвата внутри, зазоры 3 мм.
8. Проверить ход выкатной платформы C под нагрузкой (~50 кг) до выставления стопоров.

---

## 9. Что осталось открытым

- **⑤ Ревизии GGS/AC10/SF4** — обмеры реального оборудования: габариты фильтра,
  вентилятора, глушителя (огибающие в модели), фактический зазор SE3000 по Y.
- **Тип замка** (электронный / шпингалет) — отверстие в двери закладывается на раскрое.
- **Камера Wi-Fi** — модель не выбрана, кронштейн в C не спроектирован.

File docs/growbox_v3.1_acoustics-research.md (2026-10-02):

# Акустика и вентиляция — обзор решений (исследование 03.10.2026)

Сбор инженерных приёмов по тихим вентилируемым корпусам. Источники — общие
инженерные ресурсы по акустике, а также профильные обзоры по шумобоксам для
тепловыделяющего оборудования (в т.ч. шумбоксы для ASIC-майнеров — задача
«тихий корпус для нагревающегося прибора» повторяется один в один).

**Назначение документа** — обоснование решений по тишине для v3.1. Не замена
расчёту, а вводная для него.

---

## 0. Главный вывод, который меняет подход

> **STC не оценивает частоты ниже 125 Гц.**

Шкала STC (Sound Transmission Class) считается по диапазону 125–4000 Гц.
А гул вентилятора, помпы и компрессора живёт на **50–120 Гц**.

Следствие: **проектировать «на STC» для нашего шкафа бессмысленно.** Стена со
STC 55 может отлично резать речь и вовсе не держать низкочастотный гул. Ранее
принятый расчёт по массовому закону корректен только в среднем диапазоне; на
рабочих частотах вентилятора начинают доминировать **жёсткость и резонансы**,
а не масса.

Практический вывод: **низкие частоты лечатся развязкой и демпфированием,
а не утолщением стенки.**

| Частота | Длина волны | Что работает |
|---|---|---|
| 100 Гц | 3,4 м | развязка, демпфирование, изоляция источника |
| 250 Гц | 1,4 м | + масса, поглощение в полости |
| 1 кГц | 0,34 м | масса, герметичность |
| 4 кГц | 8,6 см | герметичность (любая щель) |

---

## 1. Четыре рычага — канон

Из [commercial-acoustics.com — Soundproofing 101]. Ровно четыре принципа,
пятого не существует. Любой «звукоизоляционный» товар, который не задействует
хотя бы один, не работает.

| # | Рычаг | Механизм | Эффект | Цена |
|---|---|---|---|---|
| 1 | **Масса** | массовый закон: удвоение поверхн. плотности ≈ +6 дБ | средний диапазон | низкая |
| 2 | **Развязка** | разрывает жёсткий путь вибрации | **больше всего на дБ/$** | средняя |
| 3 | **Демпфирование** | вязкоупругий слой → тепло | +5…10 STC, лучший в низких средних | средняя |
| 4 | **Поглощение** | вата в полости гасит волну между панелями | +4…8 STC | **самое дешёвое** |

Ключевая оговорка про **развязку**: она даёт максимум при грамотном
проектировании и **ноль — если её замкнуть одним винтом не туда**. Это самый
хрупкий из четырёх рычагов.

**Демпфирование** — это вязкоупругий состав между двумя жёсткими слоями
(типично Green Glue между двумя листами ГКЛ). Работает как раз там, где масса
бессильна — в низких средних.

**Поглощение в полости ≠ поглощение в помещении.** Вата между двумя панелями —
это звукоизоляция. Акустическая пена на стене — это лечение помещения. Разные
задачи, разные материалы.

---

## 2. Обходные пути (фланкинг) — «скрытый убийца»

Из того же источника + [soundproofyourstudio.com]. Идеально собранная стена
STC 55 ведёт себя как STC 40, если дверь пустотелая и розетки не загерметизированы.

Типовые обходные пути:

| Путь | Потеря | Наш случай |
|---|---|---|
| Пустотелая дверь / дверной зазор | **дверь почти всегда слабейшее звено** | есть 3 двери |
| Парные розетки «спина к спине» в одном стоечном проёме | −5…−10 STC | **есть!** розеточные блоки на перегородке |
| Сквозные проходки, общий колодец | теряем двойную стену | **есть!** сервисный канал 80 мм |
| Общий потолочный пленум над неполной перегородкой | «практически нет стены» | **есть!** модуль A над B/C |
| Жёстко соединённый воздуховод | структурный мостик | **есть!** гофра Ø100 |

Пять из пяти — ровно наши узлы. Это не случайность: у вентилируемого корпуса
все типовые обходные пути присутствуют по определению.

**Лечение:** акустический герметик на каждую проходку, сплошной контур по
полости двойной стены, порог/опускаемый уплотнитель на двери, виброразвязка
всех воздуховодов.

---

## 3. Дверь — слабейшее звено, и это надо считать

Из [soundproofyourstudio.com]. Правило простое:

> **Комната звукоизолирована не лучше, чем её дверь.**
> Стена STC 63 + дверь STC 57 = комната STC 57.

И главное — **масса двери должна догонять суммарную массу стены**:

- стена из двух слоёв 5/8" ГКЛ = 4,4 + 4,4 = 8,8 lb/ft² (≈ 43 кг/м²)
- одинарная дверь на такие стены = **8,8 lb/ft² на весь дверной лист**
- для проёма 36″×80″ (≈ 20 ft²) это **176 lb ≈ 80 кг минимум**
- если добавить демпфер (Green Glue) в стены — массу двери надо удваивать

### Проверка по нашей конструкции

| Панель | Состав | Поверхн. плотность |
|---|---|---|
| Стена | ЛДСП 18 (≈13) + MLV 2–3 (≈5) + минвата 20–30 (≈1) + обшивка (≈4–6) | **≈ 23–25 кг/м²** |
| Дверь rev.3 | ЛДСП 18 (≈13) + MLV 3 (≈5) + минвата 20 (≈0,7) | **≈ 19 кг/м²** |

Замечание: минвата почти не даёт массы (плотность 30–40 кг/м³ → 20 мм ≈
0,7 кг/м²). Она нужна как поглотитель, не как барьер.

**Вердикт: дверь легче стены примерно на 15–25%.** Это не критично (дверь
405×1700 ≈ 0,69 м² → ~13 кг на 4 петли Blum Clip, механически нормально), но
по принципу слабейшего звена **стена переплачена, а дверь — узкое место.**
Если докупать материал — не в стены, а в дверь: добавить массы (ещё слой MLV
или демпфер между жёсткими слоями).

### Но есть спорный момент: MLV

Источник аргументирует, что **Green Glue между двумя жёсткими листами работает
лучше MLV почти по всему спектру** (MLV выигрывает только на 125 Гц), и что
MLV — это в основном SEO, а не акустика.

⚠️ **Оценка достоверности: низкая.** Статья прямо говорит «я специально
скандализирую интернет», а цифры берёт из **лабораторных тестов самой компании
Green Glue**. Это конфликт интересов: производитель тестирует свой продукт против
конкурента. Считать это доказанным нельзя.

**Что можно принять как рабочую гипотезу:** вязкоупругий демпфер в низких
средних частотах работает хорошо и заслуживает места в сэндвиче. **Чего нельзя
утверждать:** что MLV бесполезен. Независимых сопоставительных данных в этом
обзоре нет.

Практический вывод — **не выбирать, а комбинировать:** MLV как масса +
демпфер как гашение резонанса. И проверять замером, а не графиком производителя.

**Что из этого следует для нас:** MLV оставляем как «тёмную лошадку» на 125 Гц
(ровно наша проблемная зона!), но **основной выигрыш должен давать демпфер**.
Если бюджет позволяет — на двери и стену лучше вязкоупругий состав между двумя
жёсткими слоями, а MLV добавить как массу.

**Осторожно с трёхслойными сборками:** три жёстких листа с двумя полостями
могут работать **хуже** двухслойной из-за резонанса. Наша дверь корректна, т.к.
минвата — не жёсткий лист, а поглотитель. Не добавлять туда третий жёсткий лист!

---

## 4. Низкочастотный шум — специфика для вентилятора

Из [home-hydroponica.ru] (гидропоника: зелень, салат, овощи, ягоды) и [ibmm.ru]
(шумбоксы для ASIC).

### Ориентиры по дБ

| Уровень | Восприятие |
|---|---|
| 35–38 дБ | слышно даже днём |
| 20–25 дБ | считается малошумным, **но ночью слышно** |
| ≤ 25–30 дБ(A) | цель для спальни (NC-25…NC-30) |

Для сравнения — шумбокс для ASIC снижает **75–85 дБ → 45–55 дБ** (уровень
холодильника). Это же честное правило для нас:

> **Шумобокс не делает систему бесшумной. Он делает её терпимой.**
> Ставить цель «абсолютный ноль» нельзя — конструкция не сойдётся.

### Замечание по закону n⁵

Закон вентиляторов «шум ∝ n⁵» описывает **один и тот же вентилятор при
изменении оборотов**. Напрямую переносить его на сравнение «один большой vs
несколько малых» нельзя. Но вывод в сторону нескольких малых всё равно
корректный, только по другим причинам:
- меньшая окружная скорость лопасти → заметно ниже аэродинамический шум;
- тоновая составляющая уходит вверх по частоте, где её легче поглотить;
- отказ одного вентилятора не снимает обдув полностью.

### Прямые участки для гашения вихрей

Если шумит не вентилятор, а вихри на входе/выходе:

- **на входе — прямой участок ≥ 1 диаметра патрубка**
- **на выходе — прямой участок ≥ 3 диаметров патрубка**

Это дёшево и даёт заметный эффект. У нас в модуле A высота 300 мм — на выход
3D = 300 мм при Ø100 ровно укладывается.

### Диффузор на конце глушителя

Диффузор на выдуве **разбивает поток → падает выходная скорость → падает шум**.
Плюс даёт регулировку. Наш пленум с решёткой 400×300 работает в эту сторону,
но диффузор стоит добавить до пленума.

### Переразмеренный фильтр как глушитель

Угольный фильтр сам по себе — шумоглушитель. Если фильтр **заметно мощнее**
вентилятора (например, 500 м³/ч на вентилятор 250 м³/ч), шум падает в разы.

У нас: фильтр SF 4" и вентилятор SF 4" подобраны «в пару» — **здесь теряем
бесплатное глушение.** Стоит рассмотреть фильтр следующего типоразмера.

---

## 5. Материалы: что реально работает

### Многослойная изоляция гофры (DIY, из home-hydroponica)

Обмотать гофру несколькими слоями, стыки проклеить:
- вспененная резина
- многослойный войлок
- гудрон на алюминиевой подложке
- стекловата / стеклоткань
- пенополиэтилен
- **автомобильная шумоизоляция** (вибропласт, бимаст, сплэн)

Требования: **влагостойкость + негорючесть.**

Порядок DIY: минвата 50 мм распарывается на два пласта по 25 мм → оборачивается
гофра → фиксация толстой нитью → сверху пенофол 2 мм → алюминиевый скотч в стыки.
**Форму гофры придать ДО обмотки** — после согнуть невозможно, порвёт вату.
Проверка: постучать по стенке изнутри и сравнить звук.

### Слоистая конструкция (из ibmm.ru, шумобокс для ASIC)

1. **Каркас:** ЛДСП/фанера/OSB/мебельный щит **16–20 мм** — «толщина важна для
   гашения низкочастотного гула». Или металлопрофиль под ГКЛ, или брус.
2. **Виброизоляция:** прокладки в точке установки прибора + виброопоры самому
   коробу (Виброфлекс, антивибрационные ножки, пористая резина).
3. **Поглотитель:** акустическая каменная вата, **плотность ≥ 30 кг/м³**,
   толщина **от 50 мм** (Rockwool Акустик Баттс, Шуманет БМ). Крепление — клей
   для минваты или дюбели-грибки.
4. **Отражатель/замыкание контура:** пенофол поверх ваты **фольгой внутрь**,
   стыки — алюминиевый скотч. «Создаёт замкнутый звукоизолирующий контур».

### Огнестойкость — жёсткое требование

**Запрещено:** пенопласт, поролон, полиэтиленовая пена. Потенциальный источник
искры + горячий воздух = прямая угроза пожара.

**Разрешено:** каменная/базальтовая вата (НГ), металл, ГКЛО, ОСП.

Важно для нас: в обсуждениях постоянно советуют «забить короб поролоном».
**Это пожароопасно.** Вата + металл + пенофол с фольгой — безопасный набор.

---

## 6. Типичные ошибки (ibmm.ru) — свериться со списком

| Ошибка | Почему плохо | Наш статус |
|---|---|---|
| Полная герметизация корпуса | перегрев, выход из строя | ✅ у нас приток заложен (лабиринт) |
| Слабое/неправильное охлаждение | перегрев | ⚠️ см. п.7 про разрежение |
| Пренебрежение виброразвязкой | «вся конструкция — один большой излучатель низкочастотного гула» | ✅ виброподвесы есть |
| Горючие материалы | пожар | ⚠️ проверить по спецификации |
| Нет мониторинга | фатальный перегрев | ✅ SensorPro + safety-слой |
| Жёстко соединённый воздуховод | акустический мостик | ❌ **надо гибкую вставку** |

Отдельная цитата про развязку:

> «Установка работающего прибора напрямую на пол или корпус превратит всю
> конструкцию в один большой излучатель низкочастотного гула, сводя на нет всю
> звукоизоляцию.»

---

## 7. Разрежение — НЕ акустический приём (исправлено)

⚠️ **Предыдущая редакция этого раздела содержала ошибку. Исправлено.**

В источнике (ibmm.ru) было заявлено, что отрицательное давление «предотвращает
утечку звука через щели». **Физически это неверно.**

Передача звука через щель определяется геометрией щели (площадь, глубина),
а не перепадом давления. Поток воздуха со скоростью несколько м/с через
неплотность не меняет акустическую передачу заметным образом.

**Что разрежение даёт на самом деле:**
- не даёт запаху и пыли выходить наружу (однонаправленный поток внутрь);
- заставляет воздух идти правильно через фильтр (фильтр строго до вентилятора);
- при правильном балансе исключает «подсос» мимо фильтра.

**Чего оно НЕ даёт:** звукоизоляции. Щель остаётся щелью — через неё звук
проходит в обе стороны одинаково.

Практический вывод: **разрежение сохраняем (оно нужно для фильтрации), но
герметизировать стыки всё равно надо физически** — герметик, уплотнитель,
замкнутый контур. Бесплатной акустики здесь нет.

Попутное следствие из того же источника: вытяжку принято делать на 10–15%
мощнее притока. Это корректное требование по балансу, но обоснование —
правильное направление потока, а не шумоподавление.

---

## 8. Практический чек-лист по нашим узлам

| № | Узел | Что сделать | Источник эффекта |
|---|---|---|---|
| 1 | Воздуховод Ø100 | гладкая труба вместо гофры; гибкая вставка после вентилятора | вихри, структурный мостик |
| 2 | Вход вентилятора | прямой участок ≥ 1D (100 мм) | вихри |
| 3 | Выход вентилятора | прямой участок ≥ 3D (300 мм), далее диффузор → пленум | вихри, скорость |
| 4 | Фильтр | рассмотреть следующий типоразмер (переразмеренный = глушитель) | бесплатное глушение |
| 5 | Разрежение | вытяжка 10–15% > притока — зафиксировать как ТЗ | акустика + запах |
| 6 | Перегородка B/C, задняя стенка | сплошной герметик по контуру полости | фланкинг |
| 7 | Розеточные блоки | загерметизировать задние стенки, не ставить «спиной к спине» | фланкинг −5…−10 STC |
| 8 | Модуль A над B/C | уплотнитель по периметру стыка, развязка | общий пленум |
| 9 | Панели | вязкоупругий демпфер между жёсткими слоями (не только MLV) | низкие частоты |
| 10 | Материалы | только НГ: каменная вата ≥30 кг/м³, металл, ГКЛО | пожар |
| 11 | Обдув | 2–4 малых вентилятора вместо одного | закон n⁵ |
| 12 | Механика | виброподвесы на всё вращающееся; демпферные опоры корпусу | структурный шум |

---

## 9. Источники

1. **commercial-acoustics.com** — Soundproofing 101: Mass, Decoupling, Damping,
   Absorption. https://commercial-acoustics.com/sound-advice/soundproofing-101/
2. **soundproofyourstudio.com** — Do Not Use MLV To Soundproof (критика MLV,
   принцип слабейшего звена, масса двери).
   https://www.soundproofyourstudio.com/blog/do-not-use-mlv-mass-loaded-vinyl-to-soundproof
3. **home-hydroponica.ru** — Шумоизоляция гроубокса: источники шума, DIY-изоляция
   гофры, глушители, диффузор, шум помпы/дросселей.
   https://home-hydroponica.ru/shumoizoljacija-growboksa/
4. **ibmm.ru** — Шумбокс для ASIC: материалы, слои, типичные ошибки, баланс
   «шумоизоляция ↔ терморегуляция», цифры 75–85 → 45–55 дБ.
   https://ibmm.ru/news/shumboks-dlya-asika-chto-eto-i-kak-sdelat-svoimi-rukami/

**Не используется как источник:** строй-репорты с форумов о скрытом выращивании
наркокультур. Общая инженерия взята из легальных отраслей (гидропоника под
овощи/зелень/ягоды, шумобоксы для вычислительной техники, акустика помещений).

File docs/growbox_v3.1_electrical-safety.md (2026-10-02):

# Электрика и электробезопасность — гроубокс v3.1 rev.3

**Статус:** проектный расчёт + однолинейная схема. Закрывает пробел в документации:
до этого в проекте была только «карта каналов» без защит и сечений.
**Дата:** 03.10.2026

**Нормативная база (РФ):**
- ПУЭ 7-е изд.
- СП 256.1325800.2016 «Электроустановки жилых и общественных зданий»
- ГОСТ Р 50571 (МЭК 60364) — электроустановки зданий
- ГОСТ Р 51326.1 (МЭК 61008-1) — УЗО без встроенной защиты от перегрузки

> ⚠️ **Монтаж силовой части — квалифицированным электриком, с испытаниями.**
> Настоящий документ — проектное обоснование, не инструкция по монтажу.

---

## 0. Ключевые риски конкретно этого объекта

| Фактор | Почему опасно | Что заложено |
|---|---|---|
| **Вода вплотную к электрике** | ток утечки, короткое через влажность | отдельное УЗО на мокрую зону, IP44+ |
| **Самодельная сборка** | неправильные соединения, скрутки | только клеммы/Wago, без скруток |
| **20 розеток в одном шкафу** | суммарная перегрузка, нагрев контактов | разделение на 5 групп с отдельными автоматами |
| **Электроника с PWM-диммированием** | УЗО типа AC не видит пульсирующие токи | **УЗО типа A**, не AC |
| **ИБП + сеть** | ложные срабатывания УЗО от зарядного тока | УЗО ставится ДО ИБП, ток утечки ИБП контролировать |
| **481 Вт непрерывно, 24/7** | нагрев, старение изоляции | термоконтроль щитка, кабель негорючий |

---

## 1. Однолинейная схема

```
   ЩИТ КВАРТИРЫ
        │  кабель ВВГнг-LS 3×2,5 мм² (L / N / PE)
        ▼
   ┌──────────────────────────────────────────────┐
   │ QF0  Вводной, C16, 1 полюс + N               │
   │ SPD  УЗИП, тип 2 (по желанию, район с сетью)  │
   │ RCD0 УЗО 30 мА, тип A, 40 А  (общее)         │
   └──────────────────────────────────────────────┘
        │
        ├──► ГР.1  СВЕТ            QF1  C10
        │        SE3000, UV30, IR16, LED-ленты
        │        (через AC10 каналы 1, 9, 10)
        │
        ├──► ГР.2  ВЕНТИЛЯЦИЯ      QF2  C10   ← на ИБП
        │        SF 4", обдув, БП 12 В
        │        (AC10 каналы 2, 3)
        │
        ├──► ГР.3  ВОДА            QF3  C10   ← ** УЗО 30 мА тип A, отдельное **
        │        перистальтика, компрессор, увлажнитель,
        │        электроклапан подачи
        │        (AC10 каналы 4, 5, 6, 11–14)
        │
        ├──► ГР.4  ЭЛЕКТРОНИКА     QF4  C6    ← на ИБП
        │        GGS Controller, ESP32, камера, датчики
        │
        └──► ГР.5  РЕЗЕРВ          QF5  C16   ← отдельно, не на ИБП
                 обогрев / осушитель / сервис
                 (AC10 каналы 15–20)
```

**Почему пять групп, а не одна:**
- авария в мокрой зоне не снимает свет и вентиляцию;
- нагруженный канал (свет 300 Вт) не греет клеммы маломощной электроники;
- при срабатывании УЗО на воде шкаф продолжает дышать — это критично для тепла.

---

## 2. Расчёт нагрузок

| Группа | Потребители | P, Вт | I при 220 В | Автомат | Кабель |
|---|---|---|---|---|---|
| 1 Свет | SE3000 300 + UV30 30 + IR16 16 + LED 15 | 361 | 1,64 А | C10 | 3×1,5 |
| 2 Вентиляция | SF4 35 + обдув 15 + БП 12 В 10 | 60 | 0,27 А | C10 | 3×1,5 |
| 3 Вода | перистальтика 15 + компрессор 15 + увлажнитель 30 + клапан 10 | 70 | 0,32 А | C10 | 3×1,5 |
| 4 Электроника | GGS 20 + ESP32 5 + камера 10 + датчики 5 | 40 | 0,18 А | C6 | 3×1,5 |
| 5 Резерв | **обогрев до 1000 Вт** (худший случай) | 1000 | 4,55 А | C16 | 3×2,5 |
| **Итого без резерва** | | **531** | **2,4 А** | | |
| **Итого с обогревом** | | **1531** | **7,0 А** | | |

**Ввод:** кабель **3×2,5 мм²**, автомат **C16**. Запас по току более чем достаточ
(7 А из 16). Здесь 2,5 мм² выбран не по току, а по механической прочности
и правилам для розеточных групп.

**Сечения внутри шкафа:**
- силовые цепи 220 В — **3×1,5 мм²** (ВВГнг-LS или NYM-J);
- резервная группа под обогрев — **3×2,5 мм²**;
- слаботочка 12/24 В — см. п. 2.1.

### 2.1 Низкое напряжение — падение напряжения

На 12 В падение критично, считать надо обязательно:

$$\Delta U = \frac{2 \cdot \rho \cdot L \cdot I}{S},\quad \rho = 0{,}0175\ \Omega \cdot мм^2/м$$

| Нагрузка | L, м | I, А | S, мм² | ΔU | % от 12 В | Вердикт |
|---|---|---|---|---|---|---|
| Актуатор 12 В, 50 Вт | 3 | 4,2 | 1,5 | 0,30 В | 2,5 % | ✅ норма |
| Обдув 12 В, 15 Вт | 3 | 1,3 | 1,5 | 0,09 В | 0,8 % | ✅ норма |
| LED-лента 24 В, 5 м, 14 Вт/м | 5 | 2,9 | 1,5 | 0,34 В | 1,4 % | ✅ норма |
| LED-лента **12 В**, то же | 5 | 5,8 | 1,5 | 0,68 В | 5,7 % | ⚠️ на пределе |

**Вывод:** LED-ленты брать **24 В, не 12 В** — и так уже заложено в rev.3
(«LED-лента 24 В» на цоколь). Просто не менять на 12 В при закупке.

**Сечение слаботочки:** 1,5 мм² хватает на все линии 12/24 В в этих пределах.
Линии датчиков RJ12 — витая пара, отдельно от силовых.

---

## 3. Защита

### 3.1 УЗО — тип A, не AC

| Тип | Что видит | Применимость |
|---|---|---|
| AC | только синусоидальный ток | ❌ **не годится** |
| **A** | синусоиду + пульсирующий постоянный | ✅ **наш выбор** |
| B | + сглаженный постоянный | для частотников, избыточно |

Обоснование: у нас драйвер SE3000 с PWM-диммированием, импульсные БП (GGS, ESP32),
ИБП с инвертором. УЗО типа AC на такой нагрузке может **не сработать в аварии**.

**Номиналы:**
- **RCD0 (общее)** — 40 А / 30 мА / тип A, селективное (задержка 100 мс), чтобы при
  аварии в группе отключалась только она;
- **RCD3 (мокрая зона)** — 25 А / 30 мА / тип A, **без задержки**, немедленно.

### 3.2 Автоматы

- **С-характеристика** (пусковые токи у помп и увлажнителя);
- отключение по перегрузке + короткому замыканию;
- селективность: вводной C16 выше нижестоящих C10/C6.

### 3.3 Заземление (TN-S)

- **Раздельные L / N / PE** на всём протяжении. Объединение N и PE (система TN-C-S
  внутри шкафа) **запрещено** — УЗО при этом работать не будет.
- **Что заземлять обязательно:**
  - металлический корпус вентилятора SF 4"
  - корпус угольного фильтра / воздуховод, если он металлический
  - DIN-рейку и металлические корпуса модулей
  - экраны кабелей (с одной стороны)
  - электроклапан воды
- **Корпус шкафа** — ЛДСП/фанера (диэлектрик), но при сборке на металлическом
  крепеже всю металлическую фурнитуру соединить в **уравнивание потенциалов (УПП)**
  и вывести на PE.
- Шина PE в модуле B, с медной жилой ≥ 2,5 мм².

### 3.4 УЗИП (по желанию, но рекомендуется)

Тип 2 на вводе. Драйвер SE3000 и GGS — электроника с дорогой заменой,
а скачки сети в жилых домах обычны. УЗИП тип 2, In 20 кА, Up ≤ 1,5 кВ.

---

## 4. Мокрая зона — отдельный раздел, потому что тут главное

Зона растений C, баки в модуле B, шланги в сервисном канале.

| Требование | Реализация |
|---|---|
| **IP-степень** | розетки и соединения — **минимум IP44**, лучше IP54; всё, что под брызги, — IP65 |
| **Высота установки** | все вводы **≥ 150 мм от пола** (уже в проекте) |
| **Отдельное УЗО** | RCD3 на группу воды, 30 мА, тип A, без задержки |
| **Ни одного соединения в мокрой зоне** | соединения — только в сухом модуле B |
| **Электроклапан воды** | нормально закрытый, обесточивается при срабатывании RCD3 |
| **Конденсат** | гермовводы PG-13.5/PG21 с уплотнением; не стыковать трассы снизу вверх |
| **Кабель** | ВВГнг-LS (не распространяет горение, малое дымо- и газовыделение) |

⚠️ **Увлажнитель и помпа — в воде и рядом с водой.** Если корпус помпы треснул,
ток пойдёт через воду. Именно поэтому RCD3 отдельный и немедленный.

---

## 5. ИБП — приоритеты отключения

ИБП 600 ВА ≈ 360–400 Вт на выходе. Ёмкость типового ИБП такого класса
(12 В, 7–9 А·ч) ≈ 85–110 Вт·ч.

| Сценарий | Нагрузка | Автономность |
|---|---|---|
| Свет + вентиляция + электроника | 401 Вт | **~15 мин** |
| Вентиляция + электроника (без света) | 100 Вт | **~1,0–1,2 ч** |
| Только электроника | 40 Вт | **~2,5–3,5 ч** |

### Правило аварийного отключения — **свет гасим первым**

```
  ПРОПАЛА СЕТЬ
      │
      ├─► НЕМЕДЛЕННО: SE3000, UV30, IR16  OFF   (−300 Вт)
      │        причина: свет — 75% тепла;
      │        при остановленной вентиляции и включённом свете
      │        камера перегревается за минуты (см. тепловой расчёт)
      │
      ├─► СОХРАНЯЕМ: вентилятор SF 4"  ON
      │        причина: снимает остаточное тепло с радиатора SE3000
      │
      ├─► СОХРАНЯЕМ: GGS, ESP32, датчики, клапан воды  ON
      │        причина: управление + защита от протечки
      │
      └─► ЧЕРЕЗ 5–10 мин: контролируемое выключение электроники,
              свет уже мёртв, вентилятор — по температуре
```

**Расчёт выгоды:** гашение света сразу даёт **~1,2 ч** на вентиляцию вместо
**15 минут** на всё. Это разница между «пережили» и «сварилось».

Реализация: реле с контролем сетевого напряжения (или Shelly Plus 1PM)
на группе 1, логика в ESP32/HA. **Критично: свет должен гаснуть без участия HA** —
поставить простое реле контроля фазы (РКН) с нормально-разомкнутым контактом.

---

## 6. Монтаж — как делать нельзя и как надо

| ❌ Запрещено | ✅ Правильно |
|---|---|
| Скрутки проводов | Wago 221 / 2273, клеммники на DIN |
| Проводка в одной куче с водой | 4 трассы разнесены: POWER / LOW VOLT / WATER / SAFETY |
| Одна клеммная колодка на всё | раздельные шины L, N, PE на DIN |
| Скрытые соединения под обшивкой | все соединения доступны при снятии панели |
| Провода с перегибом ради «красиво» | радиус изгиба ≥ 4×Ø кабеля |
| Пайка силовых линий | только клеммы + опрессовка наконечников |
| Беспорядочная маркировка | каждый провод с обеих сторон, цвет по трассе |

**Маркировка трасс (уже в rev.3 — сохранить):**
- 🟡 жёлтый — 220 В
- ⚪ белый — слаботочка
- 🔵 синий — вода
- ⚫ серый — воздух

**Медная шина PE** — отдельная, с резьбовыми зажимами под каждый элемент УПП.

---

## 7. Термоконтроль щитка

DIN-панель в модуле B: GGS + 2× AC10 + ИБП + БП. Все вместе греются,
а модуль B закрыт.

- датчик температуры **внутри DIN-панели** (DS18B20 или Aqara) → алерт при > 45 °C;
- порог 55 °C → отключение группы 5 (резерв) и алерт;
- вентиляционные прорези в DIN-панели — снизу/сверху, лабиринтом (без щелей для шума);
- **не** ставить DIN-панель над баками — конденсат + нагрев.

---

## 8. Аварийное отключение — рубильник «СТОП»

Даже при исправной автоматике нужен **ручной разрыв**:

- **Аварийная кнопка/рубильник** на видном месте модуле B, сбрасываемый вручную;
- разрывает **все силовые группы** (1, 2, 3, 5), но **не** электронику и не клапан воды;
- дублируется сценарием в HA («тревога») и физической кнопкой рядом со шкафом.

---

## 9. Чек-лист приёмки электрики

| № | Проверка | Метод |
|---|---|---|
| E1 | Заземление непрерывно, PE не соединён с N | мультиметр, тестер PE |
| E2 | УЗО срабатывает ≤ 30 мА | кнопка «ТЕСТ» + измеритель тока утечки |
| E3 | УЗО типа A реагирует на пульсирующий ток | специализированный тестер |
| E4 | Все автоматы селективны | расчёт + имитация КЗ |
| E5 | Сопротивление изоляции ≥ 0,5 МОм | мегаомметр 500 В |
| E6 | IP-коробки в мокрой зоне закрыты, гермовводы сидят | визуально + фонарь-тест |
| E7 | Маркировка всех проводов и групп | визуально |
| E8 | ИБП держит расчётную автономность | замер под нагрузкой |
| E9 | Сценарий «пропала сеть»: свет гаснет, вентиляция работает | имитация отключения |
| E10 | Аварийная кнопка «СТОП» разрывает силовые группы | имитация |
| E11 | Температура DIN-панели после 4 ч работы < 45 °C | тепловизор / датчик |
| E12 | Нагрузочный тест 4 ч на полной мощности | прогон, контроль нагрева |

**Протокол испытаний оформляется документом и подписывается электриком.**

---

## 10. Список оборудования (ориентировочно)

| Позиция | Кол-во | Назначение |
|---|---|---|
| Автомат C16, 1 полюс + N | 1 | вводной |
| Автомат C10, 1 полюс + N | 4 | группы 1–4 |
| Автомат C16, 1 полюс + N | 1 | группа 5 (резерв) |
| УЗО 40 А / 30 мА / тип A, селективное | 1 | RCD0 общее |
| УЗО 25 А / 30 мА / тип A | 1 | RCD3 мокрая зона |
| УЗИП тип 2 | 1 | ввод (опц.) |
| Кабель ВВГнг-LS 3×1,5 мм² | ~30 м | группы 1–4 |
| Кабель ВВГнг-LS 3×2,5 мм² | ~15 м | ввод + группа 5 |
| Шина PE медная 2,5 мм² | 1 | УПП |
| Wago 221 / 2273 | ~40 | соединения |
| Клеммники DIN, маркировка | комплект | монтаж |
| Реле контроля фазы (РКН) | 1 | аварийное гашение света |
| Электроклапан воды 1/2", НЗ | 1 | отсечка при протечке |
| Розетки IP44 с крышкой | 4–6 | мокрая зона |
| Кнопка аварийного «СТОП» | 1 | ручной разрыв |
| Датчик температуры DIN-панели | 1 | термоконтроль |

---

## 11. Что осталось открытым

1. **Сечение ввода в квартиру** — зависит от щита и уже проложенных линий.
   Нужен осмотр электриком.
2. **Тип УЗИП** — по качеству сети в районе.
3. **Модель электроклапана** — НЗ, 1/2", с ручным открытием (чтобы можно было
   полить при отключённой автоматике).
4. **Реальный ток утечки ИБП** — если > 10 мА, RCD0 будет ложно срабатывать;
   тогда ИБП выносить за RCD0 (но тогда он теряет защиту от утечки — обсудить
   с электриком).

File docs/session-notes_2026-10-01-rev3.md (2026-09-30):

# Сессия 2026-10-01 (поздняя) — rev.3: улучшения по концептам + главный PDF

## Модель: 6 улучшений (по итогам разбора 9 концепт-рендеров)

Все внесены в `models/v3.1/build_v31_modular.py`, пересобрано (85 деталей, 38 плоских):

1. **Три двери против провисания** — 434 + 405 + 405 мм, петли Blum Clip ×4 на дверь, зазоры 3 мм.
2. **Акустический сэндвич дверей** — ЛДСП 18 → MLV 3 → минвата 20 = 41 мм. Ключевое решение:
   сэндвич растёт **наружу** (глубина 741 вместо 700), интерьер камеры 600 мм не трогаем —
   иначе SE3000 (585 глубины) не входит.
3. **Утопленный цоколь 55 мм** (утапливание 42 мм) + LED-лента 24 В снизу — шкаф «парит».
4. **Рабочая LED-подсветка тех-колонны B** — обслуживание без света роста.
5. **Органайзер на двери B** — 3 кармана в зоне z1060–1360 (свободно от фасадов).
6. **Крышки обоих баков** + **цветные гермовводы** (жёлтый 220 В / белый слаботочка / синий вода / серый воздух).

## Рендеры

`models/v3.1/render_v31.py` — адаптация render_matplotlib под v3.1: 4 PNG (iso, front, open, cut)
с ходами механизмов (двери распахиваются, ящики выезжают).

## Главный документ

`pdf/growbox_v31_rev3.pdf` — 12 страниц: обложка, резюме, архитектура модулей, двери и сэндвич,
новое в rev.3, вертикальные бюджеты B/C, оборудование и сценарии GGS, вода/электрика/безопасность,
программа тишины, раскрой, **инструкция по сборке (12 шагов)**, регламент обслуживания,
CAD-файлы и импорт в КОМПАС, чек-лист ①–⑧.

Исходник вёрстки: `sources/pdf-build/growbox_v31_rev3.html` (WeasyPrint, стили встроены).
Инструмент: pip weasyprint 70 (поставлен в песочницу).

## Статус чек-листов

- ①②③④⑥⑦ PASS (по protocol reports/fit_check.txt)
- ⑤ Ревизии GGS/AC10/SF4 — ОТКРЫТО (нужны обмеры реального оборудования)
- ⑧ Тепловой расчёт + прогон safety-логики — ОТКРЫТО

## Заметки

- Токен GitHub для push передаётся файлом (мимо командной строки) — иначе платформа маскирует
  длинные строки. По завершении сессии — удалить токен в GitHub (Settings → Developer settings).
- Рассмотреть deploy key вместо токенов для будущих push.

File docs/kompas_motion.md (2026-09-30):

# Движение деталей в КОМПАС-3D: двери, ящики, фасады

STEP — статичный формат: он переносит **геометрию и положение**, но не «механику». Чтобы ящик
выдвигался, а дверь распахивалась прямо в КОМПАСе (можно мышью тянуть и делать анимацию),
нужно задать **связи** в сборке. Это делается один раз, минут за 20.

Файл `models/v3.1/step/growbox_v31_rev2_open.step` — та же сборка в развёрнутом состоянии
(двери открыты на 100°, ящики выдвинуты на 450 мм, фасады газлифтов подняты на 70°).
Он нужен для наглядности и проверки ходов; рабочая сборка — `growbox_v31_rev2_assembly.step`.

## Подготовка

1. Открой `growbox_v31_rev2_assembly.step` (Файл → Открыть → STEP, режим **Сборка**) → Сохранить как `.a3d`
2. Все детали уже имеют имена (`10_Дверь_камеры_C`, `29_Ящик_бака`, …) — это удобно в дереве сборки
3. Первая деталь («Боковина_левая») зафиксируй: правой кнопкой → **Зафиксировать**

## Связи по узлам

### 1. Двери шкафа (`10_Dver_B_teh-kolonna`, `10_Dver_C1_levaya`, `10_Dver_C2_pravaya`) — петли Blum Clip

Шкаф с тремя дверями: **левая** — тех-отсек B (за ней шкафчики/ящики), **две на камеру роста C**
(узкие створки против провисания: 405 мм вместо одной широкой 814 мм).

| Дверь | Размер, мм | Петли | Открывание |
|---|---|---|---|
| `10_Dver_B_teh-kolonna` | 434×1700 | Blum Clip ×4, слева | налево |
| `10_Dver_C1_levaya` | 405×1700 | Blum Clip ×4, у перегородки | налево |
| `10_Dver_C2_pravaya` | 405×1700 | Blum Clip ×4, справа | направо |

Зазоры между дверями 3 мм (запас на разбухание ЛДСП во влажной камере). Push-to-Open, без ручек.
Внутренние фасады ящиков (11–14) утоплены за левой дверью и открываются после неё.

| Связь | Что соединять | Параметры |
|---|---|---|
| **Совпадение** (тип «ось») | ось петли двери B ↔ боковина левая | — |
| **Совпадение** (тип «ось») | ось петли C1 ↔ перегородка B/C | — |
| **Совпадение** (тип «ось») | ось петли C2 ↔ боковина правая | — |
| **Параллельность** | плоскость двери ↔ плоскость боковины (не болтается) | — |
| **Угол** (ограничение) | каждая дверь ↔ корпус | 0…110° |

Тянешь створку мышью — распахивается. В КОМПАС 21+: **Сборка → Создать сборку → Связи**.
Петли Blum Clip не моделирую отдельными телами — ось связи = реальная ось чашки петли.

### 2. Выдвижные ящики (`29_Ящик_бака`, `30_Ящик_сервисный`) + фасады `11`,`12`,`13`

| Связь | Что соединять | Параметры |
|---|---|---|
| **Направляющая** (линейная) | направляющая ящика ↔ боковина/стенка B | перемещение 0…500 мм |
| **Параллельность** | дно ящика ↔ дно корпуса | — |
| **Совмещение** | фасад ↔ передняя стенка ящика (жёсткая пара) | — |

Фасад приклеивается к ящику связью **«Расстояние = 0»** по передней плоскости — тогда они едут вместе.
Ограничение хода 500 мм соответствует Blum Tandem 500 (полное выдвижение).

### 3. Фасады на газлифтах (`14_Фасад_верх_B`, `15_Фасад_A`)

| Связь | Что соединять | Параметры |
|---|---|---|
| **Совпадение** (ось) | ось верхней кромки фасада ↔ ось в боковине | — |
| **Угол** | фасад ↔ корпус | 0…70° |

### 4. Выкатная платформа камеры (`22_Платформа_выкатная`, `23_Горшок_*`)

| Связь | Что соединять | Параметры |
|---|---|---|
| **Направляющая** | платформа ↔ боковины камеры C | 0…450 мм |
| **Расстояние = 0** | горшки ↔ платформа (едут вместе) | — |
| **Расстояние** (регулировка) | платформа ↔ дно (высота ±240 мм) | задать переменной |

### 5. Свет `25_SE3000` на роликовых подвесах

| Связь | Что соединять | Параметры |
|---|---|---|
| **Направляющая** | подвесы ↔ потолок камеры | перемещение 0…300 мм по Z |

Это как раз «регулируемая высота» из ТЗ — можно проверить расстояние до канопы на любом уровне.

## Анимация и проверка ходов

- **Мышиное перетаскивание**: просто тяни деталь в рабочем окне — сборка «пойдёт» по связям
- **Сборка → Проверка сборки**: помехи и зазоры (например, ящик не цепляет бак)
- **Анимация** (КОМПАС 21+, «Механика» / «Анимация сборки»): задать углы и перемещения как
  параметры сценария — можно прогнать цикл «открыть-закрыть» и вывести видео/кадры
- Сохрани виды в `.cdw` — разрез с открытым ящиком удобен для чертежа

## Как ходы связаны с параметрами скрипта

Все углы/перемещения зашиты в `build_v31_modular.py` (блок «ВАРИАНТ ОТКРЫТО»):

```python
OPEN_ANGLE_DOOR = 100     # распашные двери (B и C1 — влево, C2 — вправо), град
OPEN_ANGLE_GAS  = 70      # фасады газлифтов, град
SLIDE_DRAWER    = 450     # выдвижение ящиков, мм (предел — Tandem 500)
SLIDE_PLATFORM  = 450     # выдвижение платформы, мм
```

Поменял → `build.bat` → новый `growbox_v31_rev2_open.step` с нужными ходами.

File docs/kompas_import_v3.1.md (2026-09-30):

# Импорт модели v3.1 rev.2 в КОМПАС-3D

Файлы в `models/v3.1/step/` и `models/v3.1/dxf/` сгенерированы как **открытые форматы** (STEP AP214 + DXF).
Нативные форматы КОМПАС (`.m3d` деталь, `.a3d` сборка, `.cdw` чертёж) создаются только внутри КОМПАС-3D —
ниже пошаговый переход от STEP к нативным файлам.

## 1. Полная сборка → `.a3d`

1. КОМПАС-3D → **Файл → Открыть** → выберать тип файла **STEP AP214 (*.stp; *.step)** →
   `models/v3.1/step/growbox_v31_rev2_assembly.step`
2. В диалоге импорта: режим **«Сборка»** (не «Единая деталь»!), структуру сохранять по именам компонентов.
   Имена деталей уже заданы (`01_Боковина_левая_B-C`, `25_SE3000`, …) — они станут именами компонентов.
3. **Файл → Сохранить как** → `growbox_v31_rev2.a3d`.
4. Если КОМПАС предложит «Выполнить пересборку» — согласиться, затем **Сервис → Проверка сборки**
   (поиск помех/зазоров).

Альтернатива: `growbox_v31_rev2_all.step` — тот же объём одним компаундом (если нужна единая деталь для
расчётов/визуализации, а не сборка).

## 2. Отдельные детали → `.m3d`

`models/v3.1/step/parts/` — 35 файлов STEP, каждая деталь отдельно (мебельные панели, ящики, фасады).
Пол и перекрытие разведены по модульно: `03_Dno_B` 418×700 (модуль B) и `03_Dno_C` 796×700 (модуль C).

1. **Файл → Открыть** → STEP → нужный файл (например `05_Перегородка_B-C_сервисная.step`).
2. КОМПАС откроет его как деталь → **Файл → Сохранить как** → `имя.m3d`.
3. Для каркасных деталей из профиля/труб — после импорта можно применить библиотеки металлопрофиля.

Совет: создайте библиотеку `GrowBox_v31/` и складывайте туда `.m3d`, чтобы сборка `.a3d` ссылалась на
локальные файлы, а не на STEP.

## 3. Раскрой и чертежи → `.cdw`

`models/v3.1/dxf/` — контуры 20 плоских деталей (карта раскроя).

1. **Файл → Открыть** → DXF → деталь (например `10_Дверь_камеры_C.dxf`).
2. Проверьте масштаб: DXF в миллиметрах 1:1, лист модели = реальный размер.
3. Создайте чертёж (`.cdw`), проставьте размеры, допуски, обозначения сверловки/фурнитуры.
4. Для раскроя ЛДСП: карта в `models/v3.1/csv/cutlist.csv` (разделитель `;`, UTF-8) —
   загрузите в оптимизатор раскроя (Cutting, Astra, Excel) перед заказом.

## 4. Именование и структура

**Важно про имена:** в STEP имена компонентов и файлы даются **транслитом** (латиницей) —
иначе КОМПАС показывает «кракозябры» вместо кириллицы (OCCT пишет UTF-8, а КОМПАС читает CP1251).
Русские наименования — в таблице соответствия **`models/v3.1/csv/names_map.csv`**: нашёл
`05_Peregorodka_B-C_servisnaya` → это «05_Перегородка_B-C_сервисная». После импорта можно
переименовать компоненты в дереве сборки по этой таблице.

| Префикс | Содержимое |
|---|---|
| `01–09` | каркас модулей B+C и опоры |
| `10–15` | фасады и двери (Push-to-Open, Blum) |
| `16–20` | воздуховодный тракт модуля A (фильтр → SF4 → глушитель → пленум → решётка) |
| `21–28` | камера роста C (поддон, платформа, горшки, SCROG, свет, датчики) |
| `29–41` | тех-колонна B (ящики, баки, увлажнитель, DIN-панель, электрика) |
| `42–56` | оборудование/фурнитура (огибающие), корпус модуля A (боковины/крышка/задняя) |

**Огибающие оборудования** (`kind=оборудование` в `csv/bom.csv`) — упрощённые тела для проверки посадки
и компоновки. Перед закупкой сверьте с реальными габаритами ревизий (чек-лист ⑤ из ТЗ).

## 5. Что проверить после импорта

- [ ] Совпадение габаритов BBox: 1250 × 718 × 2060 (с фасадами и опорами)
- [ ] Зазоры SE3000 в камере: ±96 мм по X, ±7,5 мм по Y (строгий минимум — переделать посадку, если мешает)
- [ ] Тракт в модуле A: Ø250 при внутренней высоте 282 мм — запас 32 мм, учесть виброподвесы
- [ ] Прорези перегородки B/C под гермовводы PG-13.5/PG21
- [ ] Чек-лист ②: габариты конкретных ревизий фильтра/вентилятора/глушителя (план «Б» — фильтр в камеру C)

Протокол автоматических проверок: `models/v3.1/reports/fit_check.txt`.

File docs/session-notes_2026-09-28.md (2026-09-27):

# Описание сессии — 28.09.2026 (перенос проекта в Git + инженерия v3.1)

Хронология рабочей сессии: от анализа архивов на Яндекс.Диске до инженерных документов v3.1.

---

## 1. Анализ архива «Бокс» (Яндекс.Диск)

- Изучена публичная папка: два дампа рабочего пространства `mimoclaw_workspace (11)/(14).tar.gz`.
- Полностью распакован архив (11); архив (14) **повреждён** (gzip-поток битый с середины,
  восстановлено 200 файлов из ~279; утеряно рабочее дерево `GrowBox/`). Повторное скачивание
  не помогает (MD5 совпадает с метаданными API — файл повреждён до загрузки).
- Состав: проект «Гроубокс» v3.0 — 3D-модель (STEP/STL/GLB, CadQuery), спецификация с картой
  раскроя, PDF-документация, чаты-источники, материалы сборки PDF.
- Итог анализа: комплект содержательно полный; арифметика габаритов v3.0 сходится
  (18+400+18+796+18=1250), SE3000 в зону встаёт с зазорами 96 мм.

## 2. Создание репозитория

- Содержимое распаковано и разложено по папкам: `docs/ models/ pdf/ images/ sources/` + README.
- Исключено из публикации: файлы учётных данных, персональные конфиги ассистента, `.venv`, дубликаты.
- Итог: 102 файла, ~46 МБ, git-история ведётся с этого дня.

## 3. ⚠️ Инцидент с учётными данными

- При контроле обнаружено: файл `sources/ocr_all.txt` (результат OCR) содержал текст токена
  и был запушен в публичный репозиторий.
- Принятые меры: файл удалён, git-история переписана (`filter-branch` + force-push),
  проверено отсутствие секретов в дереве и истории; все локальные токен-файлы удалены;
  архив (14) пересобран без них. Токен отозван пользователем.
- Правило, добавленное в процесс: **скан сборки на секреты до push** (grep только именами
  файлов/с маскировкой — значения секретов не должны попадать в логи).

## 4. Инженерия v3.1 — акустический техмодуль

- Верхний техотсек 300–350 мм на всю ширину: **фильтр → гибкая вставка → SF4 → гибкая вставка
  → шумоглушитель → пленум → решётка 600×250 в комнату**.
- Принцип: масса + поглощение + развязка. Стенки — сэндвич (18 ЛДСП → минвата 40 в обойме →
  зазор 20 → перфорация 8).
- Ключевые правки к исходной схеме: лабиринт и пленум объединены в один узел (перегородка
  со смещённым входом); фильтр — на отдельном виброподвесе; минвата не в потоке воздуха.
- Аэробюджет: фильтр 30–50 Па + глушитель ≤10 + прочее ≤10 ≈ ≤70 Па; решётка 0,15 м² → ≈0,4 м/с.
- Трейдофф высоты: зона растений 1964 → ~1630 мм (канопа V-SCROG ~450 мм).
- Документ: `docs/growbox_v3.1_acoustic-tech-module.md`, чертёж: `docs/drawings/acoustic-tech-module-v3.1.svg/.png`.

## 5. Инженерия v3.1 — двухкамерный шумоглушитель

- Конструкция: канальный глушитель 650×280×280, канал 160×160 за перфорацией (отв. 4–5 мм,
  25–30% открыта), минвата HVAC 40 мм в обойме, две камеры + шейка Ø120 (диссипативный +
  реактивный принципы), съёмная крышка с прокладкой.
- Расчёт: скорость в канале ≤2,4 м/с (макс), сопротивление ≤10 Па, затухание 15–20 дБ(А).
- Компоновка: ряд по ширине не влезает (1530 > 1250) → рекомендована «змейка» в две строки
  по глубине (фильтр+SF4 впереди, глушитель сзади).
- Документ: `docs/growbox_v3.1_silencer.md`, чертёж: `docs/drawings/silencer-v3.1.svg/.png`.

## 6. Сверка с внешними референсами

- Разобран параллельный чат с ChatGPT (55 сообщений): референсы SECRET BOX, PDF v3.1 / REV.2,
  идеи по каркасу и компоновке, бюджет Spider Farmer vs AC Infinity.
- К заимствованию: модульность в 3 блока на стяжках, двойная задняя стенка (сервисный канал),
  внутренний алюминиевый каркас, выкатная кассета горшков + EVA-поддон, ночной профиль работы.
- Отклонено/под вопросом: вентилятор 6" в бюджете (канон — SF 4" Ø100), «плавающие» габариты
  REV.2 (канон — 1250×700×2000), наращивание числа узлов (фичер-крип).

## 7. Крепёжная карта

- Сведены в `docs/growbox_v3.1_fasteners.md`: три контура крепления (силовой / виброразвязанный /
  сервисный), правило «крепёж под отказ», узлы зоны выращивания (актutor + SBR16 + телескопы),
  позиции крепежа с ссылками, чек-лист сборки.

## 8. Открытые вопросы к следующей сессии

1. SF 4" или 6" — финальное решение по вентилятору и тракту.
2. Выкатная платформа растений — оставляем (съедает ~150 мм высоты зоны) или нет.
3. Свести всё в единый **«Канон v3.1»** (размеры + модульность + BOM).
4. Пересобрать 3D-модель (`build_growbox_v3.py`) под v3.1: верхний модуль, глушитель, каркас.
5. Летний сценарий (сплит в спальне?) и конкретная модель Wi-Fi камеры.

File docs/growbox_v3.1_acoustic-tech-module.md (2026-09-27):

# v3.1 — верхний акустический техмодуль (шумбокс)

**Статус:** рабочее предложение к v3.1 (обсуждение 28.09.2026) · **Чертёж:** [`drawings/acoustic-tech-module-v3.1.svg`](drawings/acoustic-tech-module-v3.1.svg)
**Относительно v3.0:** вент-модуль в тех-колонне (1778–1982) заменяется отдельным верхним техотсеком на всю ширину корпуса.
> **Обновление:** покупной глушитель Ø180×300 заменён на самодельный двухкамерный — см. [`growbox_v3.1_silencer.md`](growbox_v3.1_silencer.md) и чертёж `drawings/silencer-v3.1.svg`.

---

## 1. Принцип

> **Масса + поглощение + развязка**

- **Масса** — ЛДСП/фанера стенок удерживает звук.
- **Поглощение** — минвата в полостях гасит отражения внутри камеры (не в потоке воздуха!).
- **Развязка** — виброопоры + гибкие вставки не дают мотору превращать корпус в динамик.

Одновременно решаются три задачи: шум вентилятора, вибрация корпуса, шум воздушного потока.

## 2. Воздушный тракт

```
зона растений (3× Ø120 в перекрытии)
   ↓
[ УГОЛЬНЫЙ ФИЛЬТР ]  ← отдельный виброподвес
   ↓ гибкая вставка 100
[ SF 4" ]            ← на виброопорах, на монтажной площадке
   ↓ гибкая вставка 100
[ ШУМОГЛУШИТЕЛЬ Ø180×300 ]
   ↓
[ ПЛЕНУМ ]  ← расширение + лабиринтная перегородка (нет прямого звука к решётке)
   ↓
[ РЕШЁТКА 600×250 ] → в комнату
```

**Важная оптимизация:** лабиринт и пленум — **один узел**. Вход в пленум со смещённым
относительно решётки (перегородка между ними) = и расширительная камера, и излом звукового
пути. Отдельный многопереходный лабиринт не нужен: он добавил бы сопротивление без выигрыша.

Фильтр — строго **до** вентилятора: мотор работает в чистом воздухе, а шум фильтра
глушится камерой модуля.

## 3. Стенки камеры (сэндвич, изнутри → наружу)

| Слой | Материал | Роль |
|---|---|---|
| 1 | 8 мм перфорированная обшивка | защита поглотителя, свободный вход звука |
| 2 | 20 мм воздушный зазор | развязка слоёв |
| 3 | 40 мм минвата акустическая **в обойме** (стеклоткань/фольга) | поглощение |
| 4 | 18 мм ЛДСП/фанера | масса |

**Запреты:** не оклеивать камеру открытым поролоном (пыль/волокна в тракт и на электрику);
минвату не ставить в поток воздуха; швы между слоями герметизировать (звук любит щели).

## 4. Виброизоляция

- SF4 — на **монтажной площадке 20 мм** (фанера/лист), площадка — на **4× каучуковых виброопорах**.
  Жёсткие уголки от мотора к корпусу — нельзя.
- Угольный фильтр (2–3 кг) — на **отдельных виброподвесах** (шпильки + резиновые проставки),
  не на корпусе вентилятора.
- Между фильтром / SF4 / глушителем — **гибкие вставки 100 мм** с хомутами; каждый узел
  закреплён независимо. Мотор не касается стенок.

## 5. Пленум и решётка

- Пленум: расширительная камера за глушителем, ~250×1250×300 (по фактическим габаритам).
- Решётка **600×250 = 0,15 м²**: при 220 м³/ч скорость ≈ **0,4 м/с**, при рабочих 135 м³/ч ≈ 0,25 м/с.
  Большая площадь выхода = низкий аэродинамический шум.
- Лабиринтная перегородка между входом в пленум и решёткой — крупная, без острых поворотов.

## 6. Аэродинамический бюджет

| Участок | Сопротивление |
|---|---|
| Угольный фильтр SF 4" | 30–50 Па (главный «пожиратель» статики) |
| Шумоглушитель Ø180×300 | 10–15 Па |
| Гибкие вставки, повороты, решётка | ≤10 Па |
| **Итого** | **≤ 55–75 Па** |

SF 4" (~220 м³/ч на 0 Па) при таком сопротивлении держит рабочие 80–135 м³/ч на 35–50%
мощности. Режим подбираем по датчикам T/RH, минимум ночью. **Не сужать проходы** —
дополнительный лабиринт из тонких каналов не делать.

## 7. Компоновка: габариты и расчёт высоты

Модуль высотой **350 мм** на всю ширину 1250 (по чертежу): ряд «фильтр 400 + вставка 100 +
SF4 280 + вставка 100 + глушитель 300» ≈ 1180 мм — укладывается в 1250 с запасом на хомуты.
Пленум — за рядом, глубина ~250 мм из 700.

**Честный трейдофф высоты:** модуль съедает ~330 мм внутренней высоты зоны растений
(1964 → ~1630 мм). Перескладка зоны:

| Диапазон (новый) | Модуль |
|---|---|
| 18–68 | коврик EVA + датчик протечки |
| 68–388 | 2 горшка 15 л |
| 400–850 | канопа V-SCROG (~450 мм рабочей высоты) |
| 880–950 | свет SE3000 на штоке актуатора |
| 950–1430 | шток + корпус актуатора, направляющие SCROG |
| 1430–1630 | полость для возврата воздуха в модуль (3× Ø120) |

Альтернатива (если высоты канопы не хватит): модуль только над тех-колонной + фильтр остаётся
под потолком зоны — зона сохраняет 1964, но акустика хуже (глушитель и пленум ужимаются).
Рекомендация: **сначала вариант с полным верхним модулем** (лучшая тишина — приоритет ТЗ),
канопа 450 мм для V-SCROG достаточна.

## 8. Размещение электроники

GGS Controller, 2× AC10, БП, ИБП — **вне акустической камеры**: сухая сервисная колонна
(как в v3.0, DIN-панель). Водяные магистрали — тоже отдельно. В камеру не совмещаем
вентилятор, силовую электрику и воду.

## 9. Что НЕ делаем

- ❌ не заполняем отсек толстым открытым поролоном;
- ❌ не делаем герметичный короб вокруг вентилятора без расчёта прохода;
- ❌ не ставим SF4 жёстко на ЛДСП / уголками к корпусу;
- ❌ не делаем маленькое выходное отверстие и узкий лабиринт;
- ❌ не держим открытый поглотитель рядом с горячими/электрическими узлами;
- ❌ не смешиваем в одном объёме вентилятор, электрику и воду.

## 10. Следующие шаги

1. Уточнить фактические габариты SF4, фильтра и глушителя (паспорта) → финальные размеры модуля.
2. Пересобрать 3D-модель (`build_growbox_v3.py`): новый верхний модуль, перегородки, пленум.
3. Обновить карту раскроя и карту электрики (каналы не меняются).
4. Вопрос: выход решётки — в комнату (текущий вариант) или в вентканал (требует врезки).

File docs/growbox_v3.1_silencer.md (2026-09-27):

# v3.1 — двухкамерный шумоглушитель SF 4" (своими руками)

**Статус:** рабочее предложение к v3.1 (обсуждение 28.09.2026) · **Чертёж:** [`drawings/silencer-v3.1.svg`](drawings/silencer-v3.1.svg)
**Заменяет:** покупной глушитель Ø180×300 из схемы акустического модуля.

---

## 1. Идея

Не «короб с ватой», а **канальный глушитель**: воздух идёт по центральному каналу,
вокруг — звукопоглощающий слой за перфорированным экраном. Две камеры с шейкой между
ними дают два принципа гашения сразу:

- **Диссипативный** (камера 1 и 2): минвата за перфорацией гасит средние и высокие частоты;
- **Реактивный** (шейка Ø120 между камерами + расширения): добавляет низкие частоты,
  где вата слаба (а именно там гудит мотор и лопасти).

Ожидаемое затухание **15–20 дБ(А)** — больше, чем у одного длинного глушителя той же длины.

## 2. Конструкция

| Узел | Решение |
|---|---|
| Корпус | ЛДСП/фанера **18 мм**, стыки на герметике (звук любит щели) |
| Поглотитель | Минвата HVAC 30–50 кг/м³ **в обойме** (стеклоткань/фольга), класс НГ/КМ0 |
| Канал | Перфорированный экран 8 мм (оргалит/оцинковка): отв. 4–5 мм, шаг 8–10, открытая площадь 25–30% |
| Камеры | ≈280 / ≈240 мм, между ними перегородка с шейкой Ø120 |
| Крышка | **Съёмная** (винты М6) + уплотнительная прокладка по фланцу |
| Вход/выход | Фланцы Ø100 → гибкие вставки 100 мм с хомутами с обеих сторон |

**Габарит (предварительно):** 650 × 280 × 280 мм, масса ~12–15 кг.
Канал внутри: 160×160 мм.

## 3. Цифры

| Параметр | Значение |
|---|---|
| Площадь канала 160×160 | 256 см² |
| Скорость в канале (рабочие 80–135 м³/ч) | 0,9–1,5 м/с |
| Скорость в канале (макс 220 м³/ч) | 2,4 м/с |
| Скорость в шейке Ø120 (макс) | ~5,4 м/с (локально, короткий участок) |
| Сопротивление глушителя | **≤10 Па** (не главное сопротивление системы) |
| Затухание | 15–20 дБ(А) |

Для сравнения: в «родном» канале Ø100 на максимуме скорость 7,8 м/с — там шум потока
заметен. Расширение канала внутри глушителя — главный вклад в тишину.

**Проверка по системе (без изменений):** фильтр 30–50 Па + глушитель ≤10 Па + прочее ≤10 Па
≈ **≤70 Па** — бюджет из схемы модуля держится.

## 4. Правила, которые не нарушаем

- ❌ Открытый поролон в канале — нет (пыль/волокна, пожарный риск). Только HVAC-материал
  с защищённой поверхностью за перфорацией.
- ❌ Короб не вешаем на воздуховод и не крепим жёстко к стенкам — своя полка/кронштейны,
  с обеих сторон гибкие вставки (развязка).
- ❌ Без прокладки под крышкой не работает: звук утечёт мимо поглотителя через щель.
- ✅ Ревизия раз в 6–12 мес: снять крышку, проверить поглотитель (в зоне растений пыльца
  и пыль от грунта неизбежны).
- ✅ Конденсат: тёплый влажный воздух из зоны — держим глушитель внутри тёплого модуля,
  при ревизии осматриваем торцы.

## 5. Влияние на компоновку модуля (важно!)

Прежний ряд «фильтр 400 + вставка 100 + SF4 280 + вставка 100 + глушитель 300» укладывался
в 1250. С глушителем 650 ряд становится **1530 мм — не влезает**. Два решения:

**Вариант А (рекомендую): змейка в две строки по глубине 700.**
- Передний ряд (глубина ~300): фильтр — вставка — SF4 (ось по ширине), ≈780 мм.
- Задний ряд (глубина ~300): глушитель 650 (ось по ширине) + выход в пленум и решётку.
- Разворот 90° между рядами — гибкая вставка + крупный отвод, сопротивление ≤5 Па.
- 2 строки × 300 = 600 < 664 внутренней глубины. Всё в одном верхнем модуле.

**Вариант Б: фильтр возвращается под потолок зоны растений** (как в v3.0),
ряд модуля: SF4 + вставка + глушитель 650 = 1030 мм — свободно. Минус: фильтр в рабочей
зоне, доступ через дверь; плюс — проще монтаж.

## 6. Сборка (порядок)

1. Короб 650×280×280 (18 мм), герметик по стыкам.
2. Перегородка с шейкой Ø120.
3. Экран перфорированный (короб канала 160×160) с обеих сторон перегородки.
4. Минвата 40 мм в обойме — заполнить полости вокруг канала, без зазоров и без уплотнения «в пресс».
5. Крышка на винтах М6 + прокладка.
6. Фланцы Ø100, обжим хомутами на гибких вставках; короб — на собственной полке.

## 7. Следующие шаги

1. Уточнить фланцы SF4/фильтра (факт) → финальные размеры корпуса и шейки.
2. Внести узел в 3D-модель v3.1 (вариант А компоновки).
3. Опционально: вторая шейка/камера при недостаточном затухании (есть резерв по длине 700).

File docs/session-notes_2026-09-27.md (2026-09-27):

# 2026-09-27 — Проект «Гроубокс» (3D-модель для КОМПАС)

## Контекст
Пользователь проектирует премиальный гроушкаф (2 растения, SCROG, спальня, тишина как ТЗ).
Есть 2 PDF (v1.0 `Проект_Гроушкаф.pdf` и v2.0 `Гроушкаф_Полное_описание_v2.pdf` — второй собран
Алисой с битой кодировкой кириллицы) + 2 вычитанных чата (Qwen — стратегия/железо, Алиса — модули:
pH с обучением, автодозатор, V-SCROG, зелёная подсветка, ИБП, музыка). Чаты лежат в
`.openclaw/tmp/growbox/` (qwen_chat.txt, alice_chat.txt, выкачанные через headless-браузер).

## Принятые решения (27.09.2026)
1. Свет — **SE3000** (603×585×71 мм, 300 Вт, PPF 856). SE4500 снят: не влезает в зону.
2. Вентилятор — **SF 4"** (Ø100), не 6"; тишину даём изоляцией + шумоглушителем (всё SF, без гибрида S&P).
3. Полный набор автоматики: актуатор 12В подъёма лампы, автодозатор (3 перистальтики + ESP32),
   pH-коррекция, ИБП 600 ВА, зелёная подсветка 520–540 нм, камера, датчик протечки.
4. Габариты канона v3.0: корпус **1250×700×2000**, колонна 400 внутр., зона растений **796×620×1964**,
   колодец 58 мм (раскладка 18+400+18+796+18=1250 — в v2 «450+800+80» не сходилось).

## Сделано
- 3D-модель: `growbox_v3/` — STEP (76 деталей, имена кириллицей через \X2\-эскейпы),
  STL, GLB + viewer.html, цветные рендеры (render_*.png), чертёжные SVG-превью,
  спецификация с картой раскроя (`growbox_v3_spec.md`), исходники (CadQuery 2.8,
  `build_growbox_v3.py`, `render_matplotlib.py`).
- Проверки: BBox 1250×730×2060, визуальный QA через mimo-omni (структура цельная,
  после правок: направляющие SCROG к стенам + кронштейны, датчики в горшках, хомуты фильтра).

## Техзаметки (для будущих сессий)
- STEP-кириллица от OCC приходит двойным UTF-8 (mojibake) — в build-скрипте есть
  `fix_step_unicode()` (latin-1 → utf-8 repair → \X2\-эскейпы).
- Headless Chrome не композит WebGL в скриншоты (model-viewer → пустые PNG) —
  цветные рендеры делаем через matplotlib Poly3DCollection (единый набор полигонов
  для корректной сортировки граней).
- agent-browser: Chrome в `/home/work/.agent-browser/browsers/chrome-154.../chrome`,
  нужен `AGENT_BROWSER_EXECUTABLE_PATH` (системный /opt/ms-playwright без +x).
- Скриншоты agent-browser падают в cwd его сессии (`.openclaw/tmp/growbox/`).

## Открытые вопросы
- Летний сценарий: есть ли сплит в спальне (IR AC Companion)?
- Камера: конкретная модель Wi-Fi.
- Следующий артефакт: единый PDF v3.0 «для мебельщика» (пользователь хочет, но КОМПАС был в приоритете).

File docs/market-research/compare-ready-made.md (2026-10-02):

# Обзор рынка: готовые гроубоксы — сравнение с нашим проектом

**Назначение:** собирать карточки по готовым изделиям (Авито, производители,
самоделки) и сравнивать с GrowBox v3.1 rev.3. Не закупочный список, а источник
инженерных решений и ценовых ориентиров.

**Правила сбора:** только легально доступные материалы — скриншоты, PDF-выгрузки
страниц, текст объявления, сайт производителя. Автоматический обход антибота
маркетплейсов **не используется**.

---

## Шаблон карточки (копировать для каждого товара)

```markdown
### N. <Название> — <источник>

**Источник:** <URL>
**Как получено:** PDF / скриншоты / текст
**Цена:** <руб>, <город>
**Габариты:** Ш × Г × В
**Площадь зоны роста:** м²

**Корпус / материалы:**
**Свет:**
**Вентиляция и шумоизоляция:**
**Вода / полив:**
**Автоматика и электрика:**
**Безопасность:**
**Что бросается в глаза (хорошо):**
**Что сделано плохо / не видно:**
**Что взять к нам:**
**Чего у нас лучше:**

**Сопоставимость с v3.1 rev.3:** ↑ лучше нас / ≈ сопоставимо / ↓ хуже нас
```

---

## 1. SECRET BOX / GROW AESTHETICS — Авито (разобрано 03.10.2026)

**Источник:** лот на Авито, 7 скриншотов (водяной знак Avito)
**Как получено:** скриншоты → визуальный разбор
**Цена:** не указана на кадрах
**Габариты:** высокий шкаф-пенал, ~160–170 см (по пропорциям на кадре 4)

**Корпус / материалы:** белые панели (вероятно МДФ 16–18 мм), светлый дуб/ясень
на боковых шкафах, чёрная рама. Внутренний белый вкладыш стоит **отдельным
контуром внутри внешнего шкафа** — двойная стена (кадр 5).

**Свет:** квантовая плата (красные/белые/УФ диоды) под потолком, LED-подсветка
под управляющим щитом, боковая досвет в два яруса с раздельным включением.

**Вентиляция и шумоизоляция:** по 2 квадратных вентилятора на боковину
(4 шт. на обдув), чёрная гофра между ними. Уплотнитель по периметру дверей,
массивные дверные косяки. Фильтр чёрного типа под светом.

**Вода / полив:** чёрное металлическое дно ящика (поддон), решётчатая проволочная
полка внизу зоны.

**Автоматика и электрика:** управляющий щит «SECRET BOX» — тумблеры
`START/STOP`, `ОСТОРОЖНО`, `ОБДУВ`, `СВЕТ`, `ВЕНТИЛЯЦИЯ`, стрелочные индикаторы,
блоки розеток Euro с крышками. Подписи на панелях: `Channel 1/2/3`, `BAK #1`,
`BAK #2`. `CO2 BAG` на крючке.

**Безопасность:** не видно (не разобрано на кадрах).

**Что бросается в глаза (хорошо):**
1. Двойной контур корпуса (вкладыш внутри шкафа)
2. Тяжёлые двери на массивных петлях + уплотнитель по периметру
3. Несколько медленных вентиляторов вместо одного быстрого
4. Перфорированные монтажные рейки — высота регулируется без сверления
5. Всё подписано (`Channel`, `BAK`) — при сервисе ничего не перепутать
6. Герметичный поддон

**Что сделано плохо / не видно:**
1. ❌ **Вентиляторы прикручены прямо к панели** (кадры 3, 6) — структурный мостик,
   корпус работает излучателем
2. ❌ Гофра между вентиляторами — турбулентность и шипение
3. ❌ Не видно виброразвязки в узлах примыкания
4. ❌ Слои изоляции не идентифицируются — по фото не понять, что за сэндвич
5. ❌ Не видно глушителя и пленума в тракте

**Что взять к нам:**
- Перфорированные монтажные рейки вместо фиксированных кронштейнов SCROG
  (снимает проблему «ход подвесов ±7,5 мм по Y», чек-лист ⑥)
- Размноженный обдув: 2–4 тихих вентилятора вместо одного
- Маркировку каналов — расширить наши цветные гермовводы на DIN-панель
- Проволочная полка внизу зоны — равномерный нижний приток, горшки над поддоном

**Чего у нас лучше:**
- Виброразвязка (виброподвесы + демпферные опоры) — у них вообще отсутствует
- Дверной сэндвич ЛДСП18+MLV3+вата20 — у них просто массив
- Тракт с глушителем и пленумом
- Автоматика (GGS + 2×AC10 + safety-слой) против тумблеров

**Сопоставимость:** ≈ сопоставимо по корпусу, ↓ хуже нас по шуму и вибре,
↑ лучше нас по эргономике рейк-системы

---

## 2. <следующий товар>

_(карточка заполняется по шаблону)_

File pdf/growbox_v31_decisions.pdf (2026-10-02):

### П Р О Е К Т · М О Д У Л Ь Н А Я У М Н А Я М Е Б Е Л Ь · С Е С С И Я Р Е Ш Е Н И Й

# ГРОУБОКС v3.1 · РЕШЕНИЯ

# Акустика · Тепло · Электрика · Железо Итоги инженерной сессии · всё оборудование Spider Farmer

# 34 дБ

гасит тракт — решают щели, не глушитель

481 Вт

тепловой баланс камеры

+10,6 К

перегрев при 135 м³/ч

# 26,8 дБ(А)

шум SF 4" — выбор по шуму

358 кг

вес шкафа, 386 кг/м² на пол

5

электрических групп с
защитой
Не заменяет pdf/growbox_v31_rev3.pdf · дополняет его | 3 октября 2026

# 01 Что решили за сессию

Документ фиксирует инженерные решения, принятые 3 октября 2026. Базовая конструкция (модули A/B/C, двери-сэндвич, раскрой) не менялась — меняются тракт, электрика, выбор железа и требования по монтажу.
Все расчёты воспроизводимы: скрипт | docs/airflow_thermal_calc.py | пересчитывается при изменении
параметров.

Главное решение сессии. Всё оборудование — Spider Farmer, без сторонних узлов. Тишину добираем
не заменой вентилятора, а трактом, виброразвязкой и герметичностью. Разбор вариантов (4", 6", 2-в-1) показал: самый тихий — SF 4" отдельно + отдельный угольный фильтр.
Область | Что решили | Обоснование
Акустика | Ставку делаем на щели и фланкинг, не на толщину стен | STC не оценивает <125 Гц, а гул вентилятора живёт на 50–120 Гц
Тракт | Гладкая труба Ø100, гибкая вставка, прямые 1D/3D, пленум | Весь шум тракта рождается в трубе: 4,77 м/ с на 4,7 м/с
Вентилятор | SF 4" отдельно + фильтр SF 4" отдельно. 2- в-1 — НЕ берём | 2-в-1 шумит 56 дБ и даёт всего 267 м³/ч через фильтр
Тепло | Автодимм SE3000 летом — единственный рабочий рычаг | Для +5 К нужно 287 м³/ч, тракт даёт ~135. Воздух не спасает
Электрика | 5 групп, УЗО типа A (не AC), отдельное УЗО на воду | PWM-диммер и импульсные БП дают пульсирующие токи
Безопасность | При пропадании сети гасим свет ПЕРВЫМ | Свет = 75% тепла. 15 мин → 1,2 ч автономности вентиляции
Умный дом | Zigbee-датчики на батарейках + DIN- распределение | Ни одного видимого провода, никаких «пауков»-удлинителей
Пол | ОТКРЫТО | 358 кг = 386 кг/м², это ×2,6 нормы на перекрытие
Акустика · Тепло · Электрика · Железо | Гроубокс v3.1 · инженерные решения · 2 / 12

# 02 Акустика: четыре рычага и главный вывод

Открытие, которое меняет подход. Шкала STC считается по диапазону 125–4000 Гц. А гул вентилятора, помпы и компрессора живёт на 50–120 Гц. Значит проектировать «на STC» бессмысленно, и утолщение стенки не решает главную проблему.

Частота | Длина волны | Что реально работает
100 Гц | 3,4 м | развязка, демпфирование, изоляция источника
250 Гц | 1,4 м | + масса, поглощение в полости
1 кГц | 0,34 м | масса, герметичность
4 кГц | 8,6 см | герметичность (любая щель)

## Четыре рычага — единственные, пятого нет

Рычаг | Механизм | Эффект | Цена
Масса | удвоение поверхностной плотности ≈ +6 дБ | средний диапазон | низкая
Развязка | разрывает жёсткий путь вибрации | больше всего на дБ/₽ | средняя
Демпфирование | вязкоупругий слой → тепло | +5…10 STC, лучший в низких средних | средняя
Поглощение | вата в полости гасит волну | +4…8 STC | самое дешёвое

Хрупкий рычаг. Развязка даёт максимум при грамотном проектировании и ноль — если её замкнуть одним винтом не туда. Крепёж вентилятора напрямую к панели обнуляет всю работу по шуму.

## Масса: дверь против стены

Панель | Состав | кг/м²
Стена | ЛДСП 18 (≈13) + MLV 2–3 (≈5) + минвата 20–30 (≈1) + обшивка (≈4–6) | 23–25
Дверь rev.3 | ЛДСП 18 (≈13) + MLV 3 (≈5) + минвата 20 (≈0,7) | 19

Минвата почти не даёт массы (плотность 30–40 кг/м³ → 20 мм ≈ 0,7 кг/м²) — она нужна как поглотитель. Дверь легче стены на 15–25%. По принципу слабейшего звена это узкое место: если докупать материал — не в стены, а в дверь.

# 03 Обходные пути — пять из пяти

Идеально собранная стена ведёт себя на 10–15 STC хуже паспортной, если есть неплотность. Все пять типовых обходных путей присутствуют в нашем проекте — это не случайность: у вентилируемого корпуса они есть по определению.

Путь | Потеря | Наш узел
Двери, дверные зазоры | слабейшее звено | 3 двери-сэндвич, уплотнитель по периметру
Акустика · Тепло · Электрика · Железо | Гроубокс v3.1 · инженерные решения · 3 / 12

Розетки «спиной к спине» | −5…−10 STC | розеточные блоки на перегородке B/C
Сквозной колодец, общий проход | теряем двойную стену | сервисный канал 80 мм
Общий пленум над перегородкой | «практически нет стены» | модуль A над B/C
Жёстко соединённый воздуховод | структурный мостик | гофра Ø100 → заменить

### Приоритеты вложений по дБ на рубль:

1) уплотнение дверей и щелей → 2) герметизация обходных путей двойной стены → 3) виброгасящая лента на панели → 4) уплотнитель в стыки корпуса → 5) утолщение сэндвича.

Акустика · Тепло · Электрика · Железо Гроубокс v3.1 · инженерные решения · 4 / 12

# 04 Воздушный тракт: расчёт

## Скорости по сечениям (135 м³/ч)

Сечение | S, м² | v, м/с | Скоростное давление | Оценка
Воздуховод Ø100 | 0,0079 | 4,77 | 13,7 Па | шумит
Пленум 600×250 | 0,150 | 0,25 | 0,04 Па | тихо
Решётка 400×300 | 0,120 | 0,31 | 0,06 Па | тихо

Весь шум тракта рождается в одном метре трубы. Пленум и решётку волноваться не за что (0,25–0,31 м/с). Замена гофры на гладкую трубу + прямые участки 1D/3D — дешёвый выигрыш.

## Сопротивление системы

Элемент | dP, Па | Примечание
Угольный фильтр SF 4" | 50,0 | половина всего сопротивления
Трение в трубе Ø100, 2 м | 6,5 | при гофре ×2–3
Колена 90° ×2 | 19,1 | плавные = меньше
Шумоглушитель двухкамерный | 15,0 | —
Пленум + решётка | 13,8 | —
ИТОГО | 104,4 | Re ≈ 31 800, f = 0,0237

Рабочая точка ≈ 125–135 м³/ч — верх диапазона по ТЗ. Резерва почти нет: вентилятор крутится на 60– 70% (для шума хорошо), но при засорении фильтра расход упадёт. Менять уголь по регламенту, не откладывать.

## Шум: контринтуитивный результат

## 48,6 дБ(А)

источник: вентилятор на рабочей точке

−34 дБ

гасит тракт (фильтр 8 + глушитель 18 + пленум 8)

## 14,6 дБ(А)

| | на выходе решётки

34 дБ затухания — больше, чем нужно. Если бы схема работала целиком, мы бы ничего не слышали. Следовательно тишину выигрывают не трактом, а щелями: любая неплотность обнуляет эти 34 дБ быстрее, чем любой глушитель их добавит. Не тратиться на более толстый глушитель.

Акустика · Тепло · Электрика · Железо Гроубокс v3.1 · инженерные решения · 5 / 12

# 05 Тепловой баланс камеры

## Источники тепла

Источник | P, Вт
SE3000 (свет) | 300
UV30 + IR16 | 46
Вентилятор SF 4" + обдув | 50
Перистальтика + компрессор | 30
GGS + 2× AC10 + ИБП + LED-ленты | 55
ИТОГО, свет включён | 481
ИТОГО, тёмная фаза | 100

## Перегрев над притоком (приток 24 °C)

Расход, м³/ч | Свет ВКЛ (481 Вт) | Тёмная фаза (100 Вт)
80 | 17,9 К → 41,9 °C | 3,7 К
120 | 12,0 К → 36,0 °C | 2,5 К
135 | 10,6 К → 34,6 °C | 2,2 К

Воздухообменом тепловой режим НЕ решается. Чтобы удержать +5 К (камера 29 °C), нужно 287 м³/ч. Тракт даёт ~135. Это физика: 481 Вт в 0,85 м³.

## Что реально работает, по возрастанию цены

Вариант | Результат | Комментарий
Автодимм SE3000 | 200 Вт → +8,4 К 150 Вт → +7,3 К | У драйвера есть регулятор. Почти бесплатно, единственный эффективный рычаг
Вентилятор 6" / второй в контуре | ~179 м³/ч → +8 К | Громче, ломает «всё SF 4"»
Внешний кондиционер | закрывает полностью | Открытый вопрос «летний сценарий»

Тёмная фаза проблем не создаёт: 2–4 К даже на минимальном расходе.

Акустика · Тепло · Электрика · Железо Гроубокс v3.1 · инженерные решения · 6 / 12

# 06 Выбор железа: SF 4" vs SF 6" vs 2-в-1

Разобраны паспортные данные производителя. Сравнение — по двум осям сразу: шум и воздух на наших рабочих кубах, а не на полном газу.

## Паспортные данные

Параметр | SF 4" | SF 6" | 2-в-1 (6")
Воздух на 0 Па | 205 CFM = 348 м³/ч | 402 CFM = 683 м³/ч | 305 CFM = 518 м³/ч
Воздух через фильтр | ~120–150 CFM (оценка) | — | 157 CFM = 267 м³/ч
Обороты | — | — | 3750 об/мин
Мощность | — | — | 48 Вт ±5%
Шум (макс) | 26,8 дБ(А) | 32 дБ(А) | 56 дБ (в FAQ 60)
Габариты упаковки | — | — | 538 × 310 × 240 мм
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

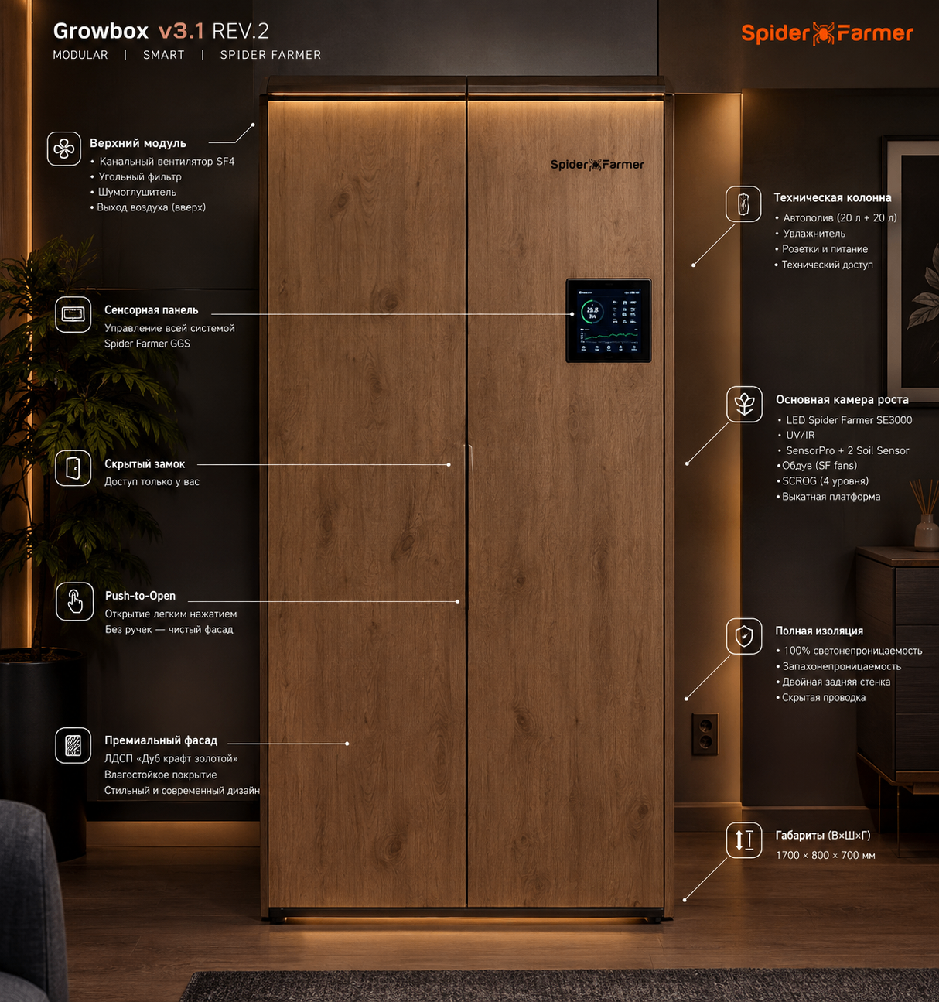
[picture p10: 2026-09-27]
images/concepts/ai_06_21-18.png

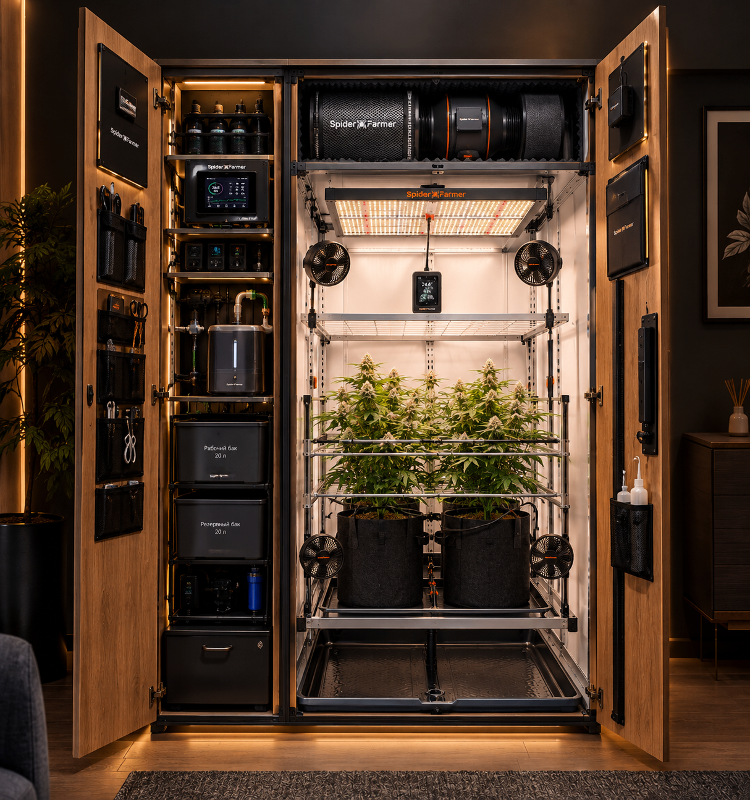
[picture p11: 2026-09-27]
images/concepts/ai_07_21-19.png

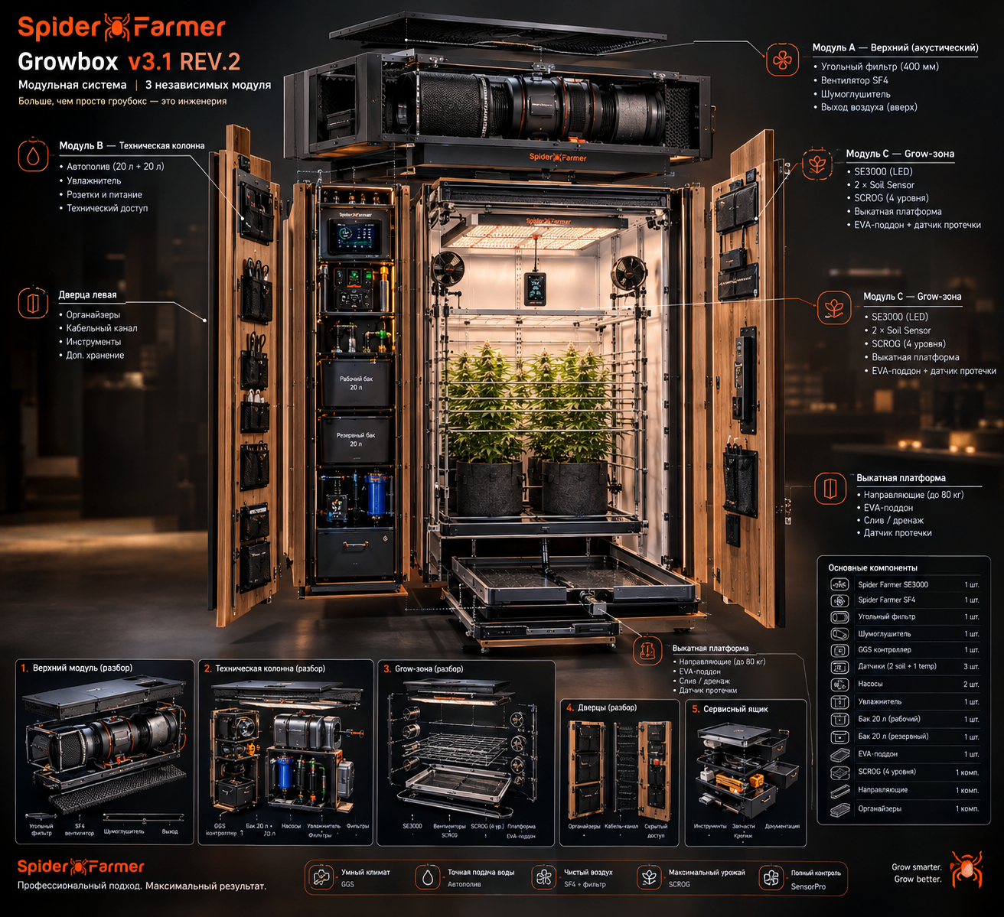
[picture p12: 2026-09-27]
images/concepts/ai_03_21-32.png

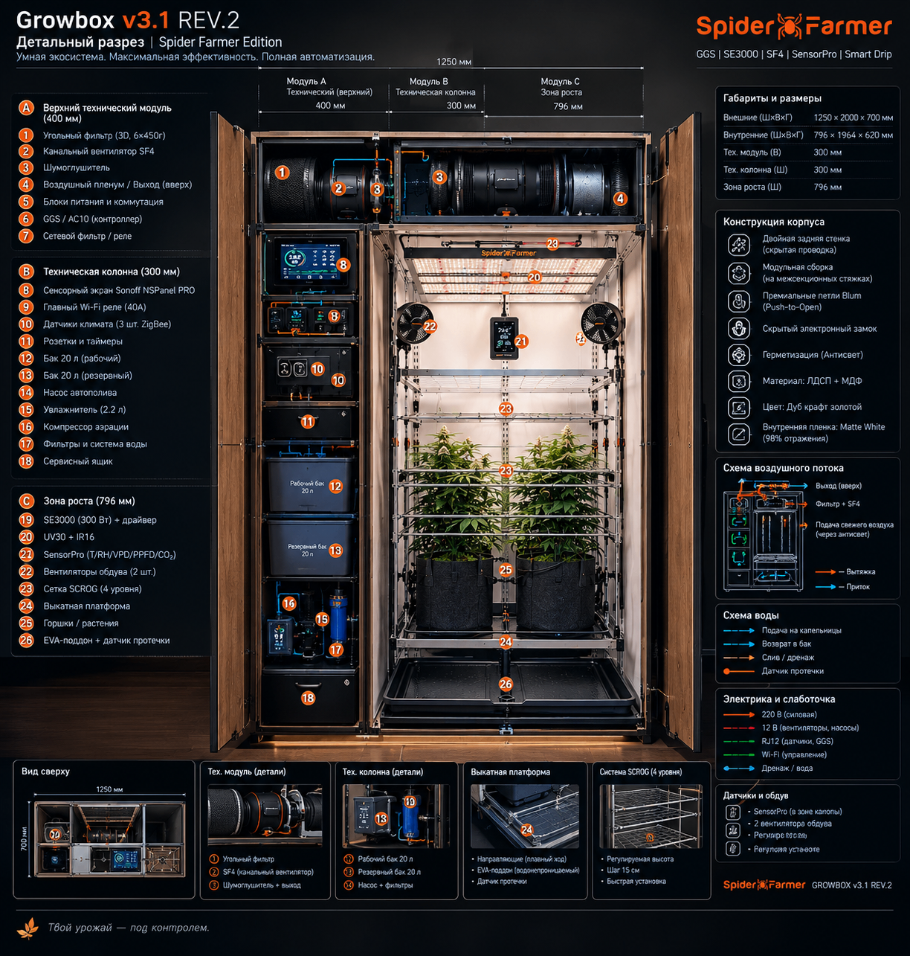
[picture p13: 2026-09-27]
images/concepts/ai_04_21-23.png

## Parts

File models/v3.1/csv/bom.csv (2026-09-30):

№ | Наименование | Кол-во | Тип | Модуль
1 | 01_Боковина_левая_B-C | 1 | деталь | B+C
2 | 02_Боковина_правая_B-C | 1 | деталь | B+C
3 | 03_Дно_B | 1 | деталь | B
4 | 03_Дно_C | 1 | деталь | C
5 | 04_Полка-перекрытие_B | 1 | деталь | B
6 | 04_Полка-перекрытие_C | 1 | деталь | C
7 | 05_Перегородка_B-C_сервисная | 1 | деталь | B+C
8 | 06_Задняя_внутр_B | 1 | деталь | B+C
9 | 07_Задняя_внутр_C | 1 | деталь | B+C
10 | 08_Задняя_наружная_B-C | 1 | деталь | B+C
11 | 09_Опора_демпферная_1 | 4 | фурнитура | B+C
12 | 09_Опора_демпферная_2 | 4 | фурнитура | B+C
13 | 09_Опора_демпферная_3 | 4 | фурнитура | B+C
14 | 09_Опора_демпферная_4 | 4 | фурнитура | B+C
15 | 46_Цоколь_передний | 1 | фурнитура | B+C
16 | 47_LED_подсветка_цоколя | 1 | фурнитура | B+C
17 | 48_LED_подсветка_B | 1 | фурнитура | B
18 | 59_Гермоввод_воздух_100 | 1 | фурнитура | B+C
19 | 59_Гермоввод_вода_40 | 1 | фурнитура | B+C
20 | 59_Гермоввод_слаботочка_25 | 3 | фурнитура | B+C
21 | 59_Гермоввод_силовой_20 | 1 | фурнитура | B+C
22 | 10_Дверь_B | 1 | деталь | B
23 | 53_Вкладыш_MLV_B | 1 | фурнитура | B
24 | 54_Вкладыш_минваты_B | 1 | фурнитура | B
25 | 10_Дверь_C1 | 1 | деталь | C
26 | 55_Вкладыш_MLV_C1 | 1 | фурнитура | C
27 | 56_Вкладыш_минваты_C1 | 1 | фурнитура | C
28 | 10_Дверь_C2 | 1 | деталь | C
29 | 57_Вкладыш_MLV_C2 | 1 | фурнитура | C
30 | 58_Вкладыш_минваты_C2 | 1 | фурнитура | C
31 | 60_Органайзер_двери_B | 1 | фурнитура | B
32 | 61_Карман_органайзера_1 | 3 | фурнитура | B
33 | 61_Карман_органайзера_2 | 3 | фурнитура | B
34 | 61_Карман_органайзера_3 | 3 | фурнитура | B
35 | 11_Фасад_ящика_бака | 1 | деталь | B
36 | 12_Фасад_ящика_сервиса | 1 | деталь | B
37 | 13_Фасад_секрет-бокса | 1 | деталь | B
38 | 14_Фасад_верх_B_газлифты | 1 | деталь | B
39 | 15_Фасад_A | 1 | деталь | A
40 | 64_Вкладыш_MLV_A | 1 | фурнитура | A
41 | 65_Вкладыш_минваты_A | 1 | фурнитура | A
42 | 42_Боковина_A_левая | 1 | деталь | A
43 | 43_Боковина_A_правая | 1 | деталь | A
44 | 44_Крышка_A | 1 | деталь | A
45 | 45_Задняя_A | 1 | деталь | A
46 | 16_Корпус_фильтра_SF4 | 1 | оборудование | A
47 | 17_Вентилятор_SF4 | 1 | оборудование | A
48 | 18_Шумоглушитель | 1 | оборудование | A
49 | 19_Пленум_выходной | 1 | оборудование | A
50 | 20_Решётка_400x300 | 1 | фурнитура | A
51 | 21_Поддон_EVA | 1 | оборудование | C
52 | 22_Платформа_выкатная | 1 | деталь | C
53 | 23_Горшок_15л_1 | 2 | оборудование | C
54 | 23_Горшок_15л_2 | 2 | оборудование | C
55 | 24_SCROG_V-рамка_уровень_1 | 4 | деталь | C
56 | 24_SCROG_V-рамка_уровень_2 | 4 | деталь | C
57 | 24_SCROG_V-рамка_уровень_3 | 4 | деталь | C
58 | 24_SCROG_V-рамка_уровень_4 | 4 | деталь | C
59 | 25_SE3000 | 1 | оборудование | C
60 | 26_UV30_IR16_бар_1 | 2 | оборудование | C
61 | 26_UV30_IR16_бар_2 | 2 | оборудование | C
62 | 27_Роликовый_подвес_1 | 4 | фурнитура | C
63 | 27_Роликовый_подвес_2 | 4 | фурнитура | C
64 | 27_Роликовый_подвес_3 | 4 | фурнитура | C
65 | 27_Роликовый_подвес_4 | 4 | фурнитура | C
66 | 28_SensorPro | 1 | оборудование | C
67 | 29_Ящик_бака | 1 | деталь | B
68 | 30_Ящик_сервисный | 1 | деталь | B
69 | 31_Бак_рабочий_20л | 1 | оборудование | B
70 | 62_Крышка_бака_рабочего | 1 | фурнитура | B
71 | 32_Насос_полива_компрессор | 1 | оборудование | B
72 | 33_Полка_секрет-бокса | 1 | деталь | B
73 | 34_Увлажнитель_SF_5л | 1 | оборудование | B
74 | 35_Панель_DIN_съёмная | 1 | деталь | B
75 | 36_GGS_Controller | 1 | оборудование | B
76 | 37_AC10_1 | 2 | оборудование | B
77 | 37_AC10_2 | 2 | оборудование | B
78 | 38_ИБП_600ВА | 1 | оборудование | B
79 | 39_Полка_резервного_бака | 1 | деталь | B
80 | 40_Рама_полки_30x30_1 | 4 | деталь | B
81 | 40_Рама_полки_30x30_2 | 4 | деталь | B
82 | 40_Рама_полки_30x30_3 | 4 | деталь | B
83 | 40_Рама_полки_30x30_4 | 4 | деталь | B
84 | 41_Бак_резервный_20л | 1 | оборудование | B
85 | 63_Крышка_бака_резервного | 1 | фурнитура | B

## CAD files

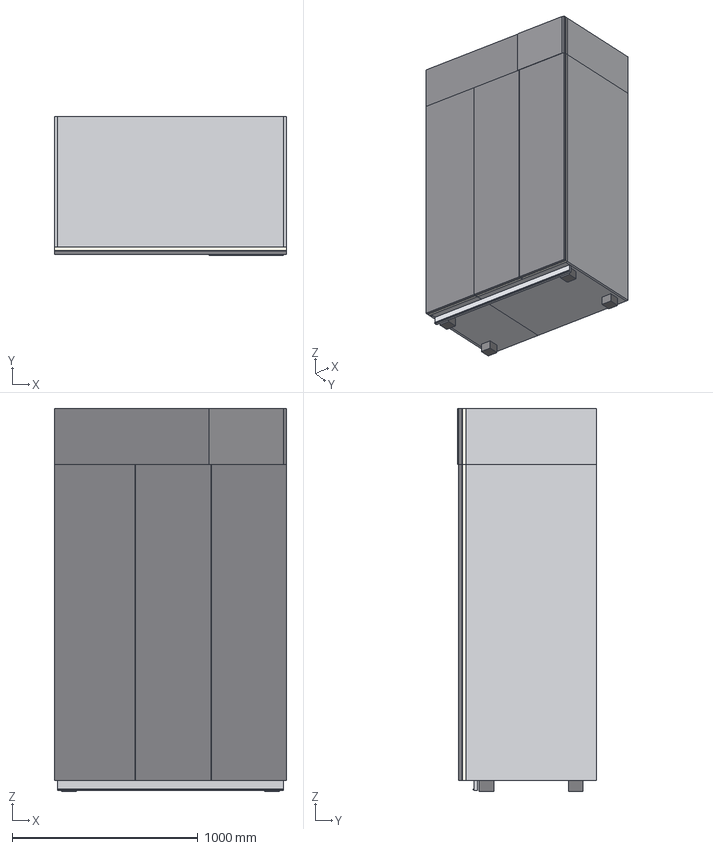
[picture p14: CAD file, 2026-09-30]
models/v3.1/step/growbox_v31_rev2_assembly.step
1250.0 x 745.0 x 2060.0 mm
01_Bokovina_levaya_B-C
02_Bokovina_pravaya_B-C
03_Dno_B
03_Dno_C
04_Polka-perekrytie_B
04_Polka-perekrytie_C
05_Peregorodka_B-C_servisnaya
06_Zadnyaya_vnutr_B
07_Zadnyaya_vnutr_C
08_Zadnyaya_naruzhnaya_B-C
09_Opora_dempfernaya_1
09_Opora_dempfernaya_2
09_Opora_dempfernaya_3
09_Opora_dempfernaya_4
10_Dver_B
10_Dver_C1
10_Dver_C2
11_Fasad_yaschika_baka
12_Fasad_yaschika_servisa
13_Fasad_sekret-boksa
14_Fasad_verh_B_gazlifty
15_Fasad_A
16_Korpus_filtra_SF4
17_Ventilyator_SF4
18_Shumoglushitel
19_Plenum_vyhodnoy
20_Reshetka_400x300
21_Poddon_EVA
22_Platforma_vykatnaya
23_Gorshok_15l_1
23_Gorshok_15l_2
24_SCROG_V-ramka_uroven_1
24_SCROG_V-ramka_uroven_2
24_SCROG_V-ramka_uroven_3
24_SCROG_V-ramka_uroven_4
25_SE3000
26_UV30_IR16_bar_1
26_UV30_IR16_bar_2
27_Rolikovyy_podves_1
27_Rolikovyy_podves_2
27_Rolikovyy_podves_3
27_Rolikovyy_podves_4
28_SensorPro
29_Yaschik_baka
30_Yaschik_servisnyy
31_Bak_rabochiy_20l
32_Nasos_poliva_kompressor
33_Polka_sekret-boksa
34_Uvlazhnitel_SF_5l
35_Panel_DIN_semnaya
36_GGS_Controller
37_AC10_1
37_AC10_2
38_IBP_600VA
39_Polka_rezervnogo_baka
40_Rama_polki_30x30_1
40_Rama_polki_30x30_2
40_Rama_polki_30x30_3
40_Rama_polki_30x30_4
41_Bak_rezervnyy_20l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

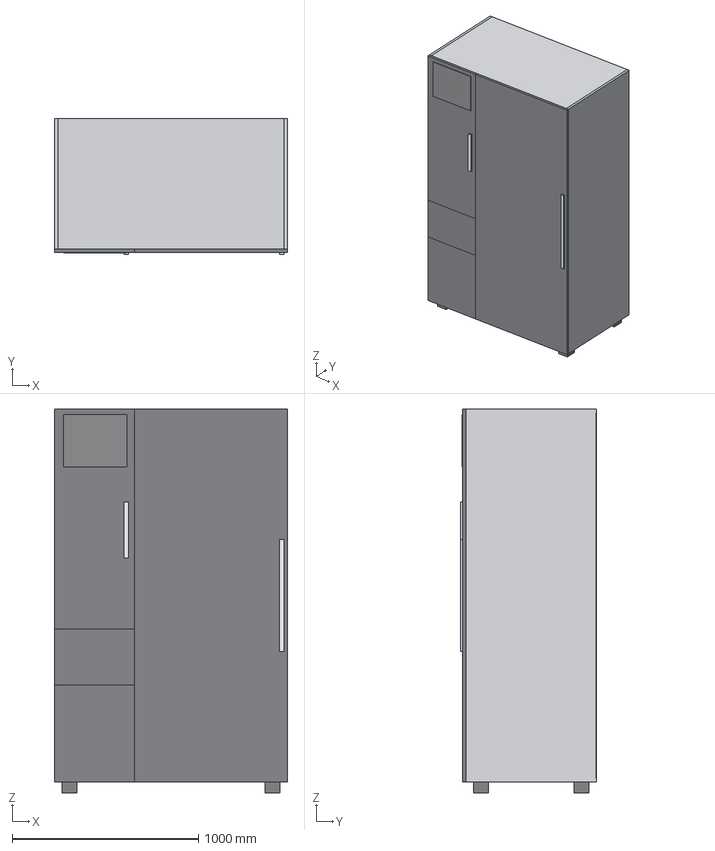
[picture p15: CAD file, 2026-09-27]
models/growbox_v3.step
1250.0 x 730.0 x 2060.0 mm
Боковина_левая
Боковина_правая
Крышка
Дно
Перегородка_ сервисная
Задняя_стенка_ техзоны
Задняя_стенка_зоны_ роста
Оргалит_колодца
Опора_1
Опора_2
Опора_3
Опора_4
Дверь_зоны_роста
Фасад_техзоны_верх
Фасад_ящика_помпа
Фасад_ящика_бак
Ручка_двери
Ручка_техзоны
Решётка_выхода_в_ комнату
Ящик_бака
Ящик_насосов
Полка_секретбокс
Панель_электроники
Полка_бака_ резервного
Бак_рабочий_20л
Бак_резервный_20л
Поплавковый_клапан
Увлажнитель_SF_5л
Камера_WiFi
ИБП_600ВА
Дозатор_удобрений
pH_модуль
AC10_№1
AC10_№2
GGS_Controller
БП_12В
Вентилятор_SF_4
Шумоглушитель
Воздуховод_Ø100
Виброподвесы_ вентилятора
Коврик_EVA_с_бортами
Горшок_1_15л
Горшок_2_15л
Направляющая_SCROG_L
Направляющая_SCROG_R
SCROG_рама_перед
SCROG_рама_зад
SCROG_рама_лево
SCROG_рама_право
SCROG_борт_передний
SCROG_борт_задний
SCROG_сетка
Кронштейн_SCROG_1
Кронштейн_SCROG_2
Кронштейн_SCROG_3
Кронштейн_SCROG_4
SE3000_каркас
SE3000_бара_1
SE3000_бара_2
SE3000_бара_3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

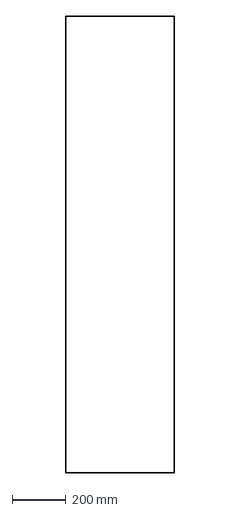
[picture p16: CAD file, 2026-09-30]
models/v3.1/dxf/58_Vkladysh_minvaty_C2.dxf
405.0 x 1700.0 mm

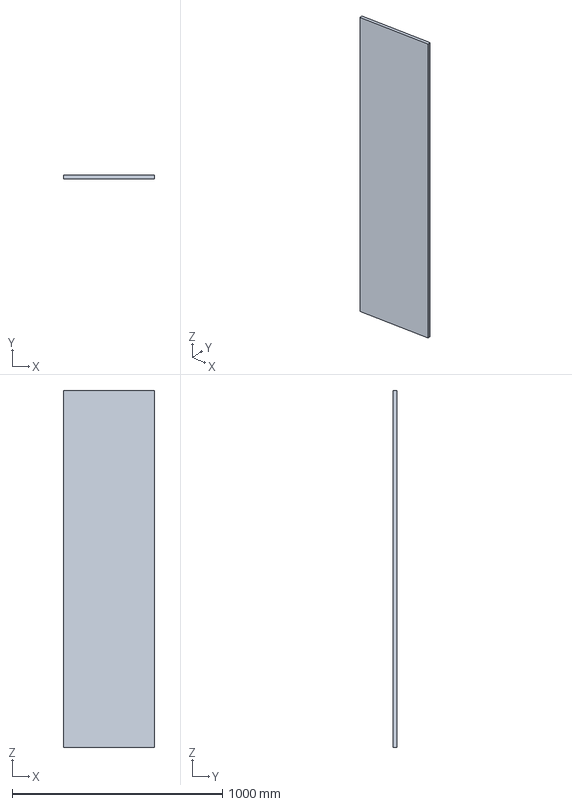
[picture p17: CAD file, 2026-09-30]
models/v3.1/step/parts/10_Dver_B.step
434.0 x 18.0 x 1700.0 mm

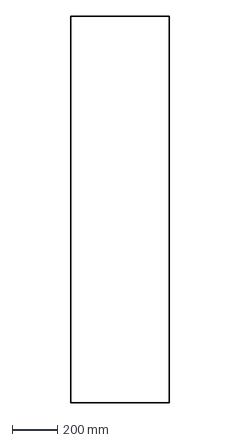
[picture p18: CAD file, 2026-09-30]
models/v3.1/dxf/54_Vkladysh_minvaty_B.dxf
434.0 x 1700.0 mm

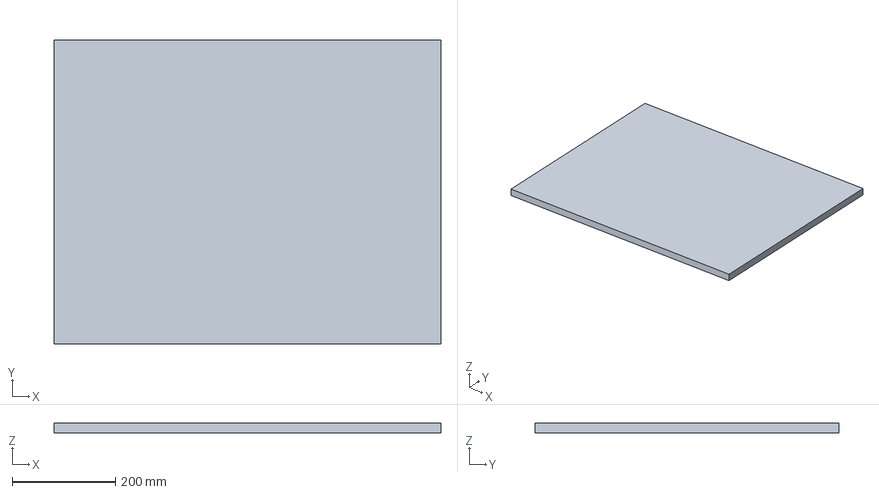
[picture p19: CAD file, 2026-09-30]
models/v3.1/step/parts/22_Platforma_vykatnaya.step
750.0 x 590.0 x 20.0 mm

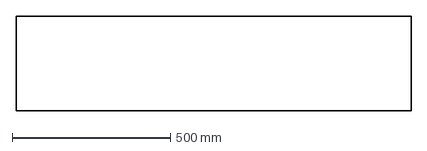
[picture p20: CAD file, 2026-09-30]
models/v3.1/dxf/65_Vkladysh_minvaty_A.dxf
1250.0 x 300.0 mm

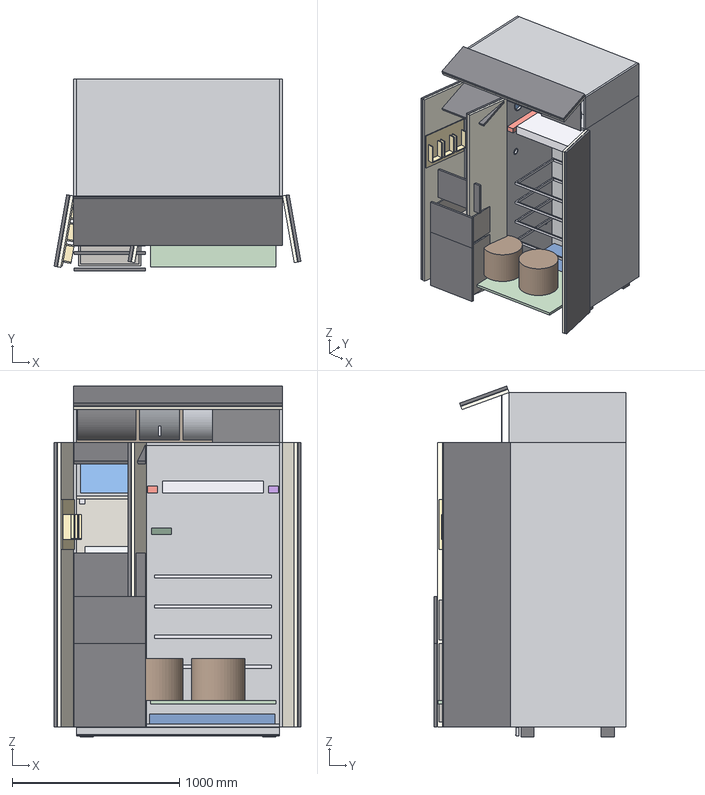
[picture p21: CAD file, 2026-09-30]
models/v3.1/step/growbox_v31_rev2_open.step
1476.4 x 1150.0 x 2098.5 mm
01_Bokovina_levaya_B-C
02_Bokovina_pravaya_B-C
03_Dno_B
03_Dno_C
04_Polka-perekrytie_B
04_Polka-perekrytie_C
05_Peregorodka_B-C_servisnaya
06_Zadnyaya_vnutr_B
07_Zadnyaya_vnutr_C
08_Zadnyaya_naruzhnaya_B-C
09_Opora_dempfernaya_1
09_Opora_dempfernaya_2
09_Opora_dempfernaya_3
09_Opora_dempfernaya_4
10_Dver_B
10_Dver_C1
10_Dver_C2
11_Fasad_yaschika_baka
12_Fasad_yaschika_servisa
13_Fasad_sekret-boksa
14_Fasad_verh_B_gazlifty
15_Fasad_A
16_Korpus_filtra_SF4
17_Ventilyator_SF4
18_Shumoglushitel
19_Plenum_vyhodnoy
20_Reshetka_400x300
21_Poddon_EVA
22_Platforma_vykatnaya
23_Gorshok_15l_1
23_Gorshok_15l_2
24_SCROG_V-ramka_uroven_1
24_SCROG_V-ramka_uroven_2
24_SCROG_V-ramka_uroven_3
24_SCROG_V-ramka_uroven_4
25_SE3000
26_UV30_IR16_bar_1
26_UV30_IR16_bar_2
27_Rolikovyy_podves_1
27_Rolikovyy_podves_2
27_Rolikovyy_podves_3
27_Rolikovyy_podves_4
28_SensorPro
29_Yaschik_baka
30_Yaschik_servisnyy
31_Bak_rabochiy_20l
32_Nasos_poliva_kompressor
33_Polka_sekret-boksa
34_Uvlazhnitel_SF_5l
35_Panel_DIN_semnaya
36_GGS_Controller
37_AC10_1
37_AC10_2
38_IBP_600VA
39_Polka_rezervnogo_baka
40_Rama_polki_30x30_1
40_Rama_polki_30x30_2
40_Rama_polki_30x30_3
40_Rama_polki_30x30_4
41_Bak_rezervnyy_20l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

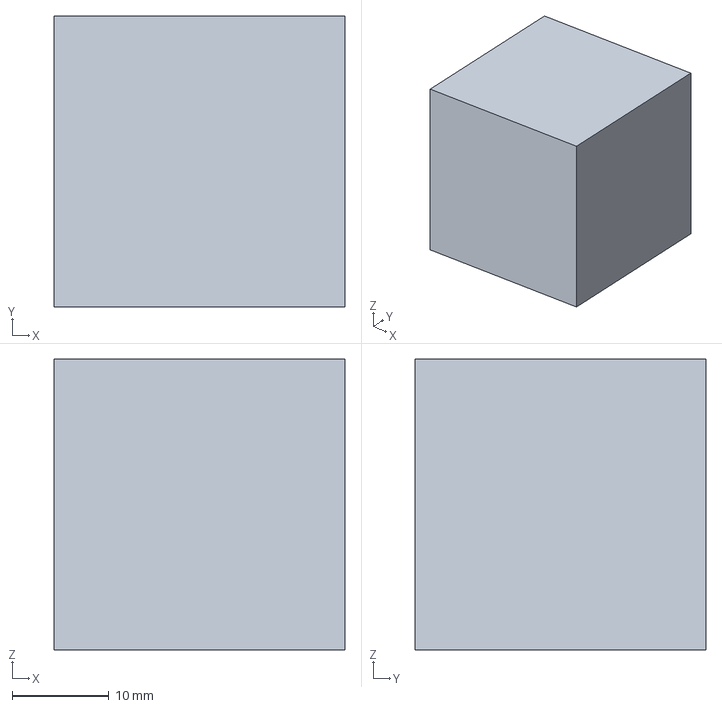
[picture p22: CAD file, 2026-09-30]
models/v3.1/step/parts/40_Rama_polki_30x30_1.step
30.0 x 30.0 x 30.0 mm

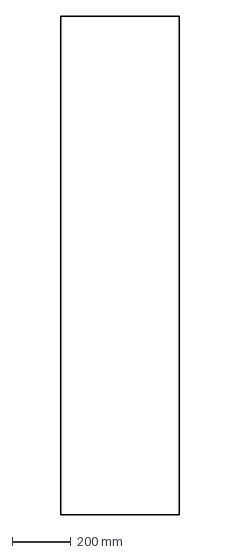
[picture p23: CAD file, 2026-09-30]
models/v3.1/dxf/55_Vkladysh_MLV_C1.dxf
405.0 x 1700.0 mm

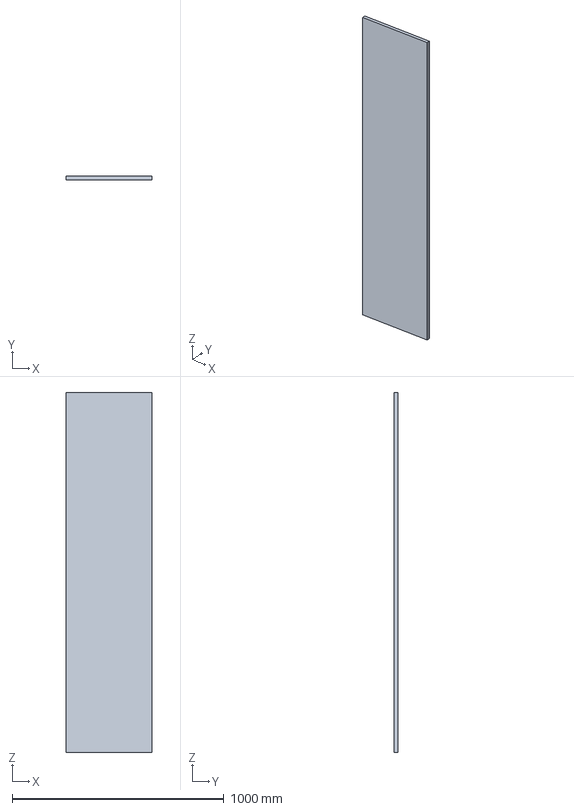
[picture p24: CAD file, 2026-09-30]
models/v3.1/step/parts/10_Dver_C2.step
405.0 x 18.0 x 1700.0 mm

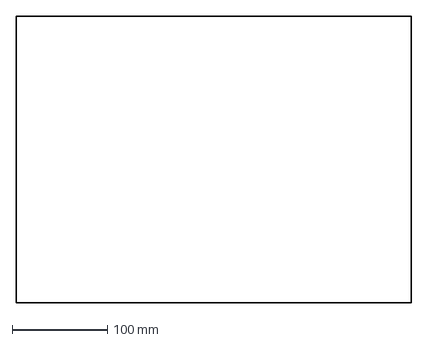
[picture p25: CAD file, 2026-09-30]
models/v3.1/dxf/60_Organayzer_dveri_B.dxf
414.0 x 300.0 mm

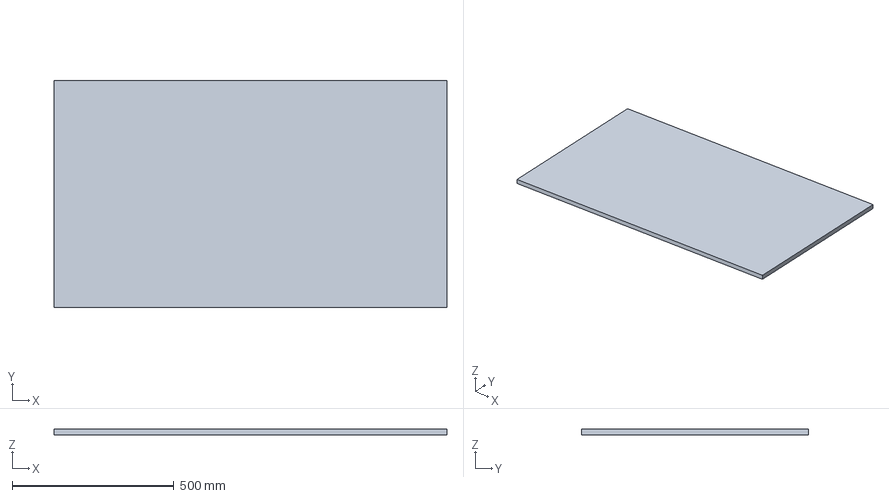
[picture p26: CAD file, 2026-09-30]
models/v3.1/step/parts/44_Kryshka_A.step
1214.0 x 700.0 x 18.0 mm

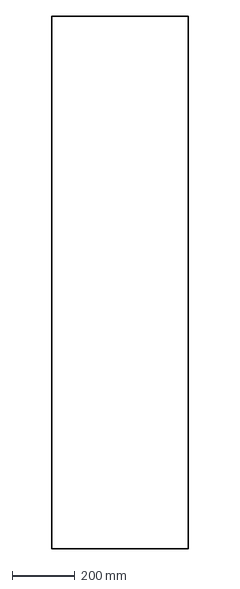
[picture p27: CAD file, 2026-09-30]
models/v3.1/dxf/53_Vkladysh_MLV_B.dxf
434.0 x 1700.0 mm

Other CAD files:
models/v3.1/step/growbox_v31_rev2_all.step
models/v3.1/step/growbox_v31_rev2.stl
models/v3.1/step/parts/07_Zadnyaya_vnutr_C.step
models/v3.1/dxf/64_Vkladysh_MLV_A.dxf
models/growbox_v3.stl
models/v3.1/dxf/01_Bokovina_levaya_B-C.dxf
models/v3.1/dxf/02_Bokovina_pravaya_B-C.dxf
models/v3.1/dxf/03_Dno_B-C.dxf
models/v3.1/dxf/03_Dno_B.dxf
models/v3.1/dxf/03_Dno_C.dxf
models/v3.1/dxf/04_Polka-perekrytie_B-C_A.dxf
models/v3.1/dxf/04_Polka-perekrytie_B.dxf
models/v3.1/dxf/04_Polka-perekrytie_C.dxf
models/v3.1/dxf/05_Peregorodka_B-C_servisnaya.dxf
models/v3.1/dxf/06_Zadnyaya_vnutr_B.dxf
models/v3.1/dxf/07_Zadnyaya_vnutr_C.dxf
models/v3.1/dxf/08_Zadnyaya_naruzhnaya_B-C.dxf
models/v3.1/dxf/10_Dver_B.dxf
models/v3.1/dxf/10_Dver_B_teh-kolonna.dxf
models/v3.1/dxf/10_Dver_C1.dxf
models/v3.1/dxf/10_Dver_C1_levaya.dxf
models/v3.1/dxf/10_Dver_C2.dxf
models/v3.1/dxf/10_Dver_C2_pravaya.dxf
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

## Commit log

2026-09-27 Гроубокс v3.1 rev.2: документация, 3D-модели, PDF, рендеры, исходные материалы
    Структурированная раскладка: docs/ models/ pdf/ images/ sources/
    [growbox_v3.step, growbox_v3.stl]
2026-09-27 v3.1: верхний акустический техмодуль — спецификация и инженерный чертёж
    - Сэндвич-стенки (масса + поглощение + развязка)
    - SF4 на виброопорах + монтажная площадка, фильтр на отдельном подвесе
    - Гибкие вставки, шумоглушитель, пленум с лабиринтной перегородкой
    - Аэродинамический бюджет ≤70 Па, решётка 600×250 (≈0,4 м/с)
2026-09-27 v3.1: самодельный двухкамерный шумоглушитель SF4 — расчёт и чертёж
    - Диссипативный (минвата за перфорацией) + реактивный (шейка Ø120) принцип
    - Канал 160×160: скорость ≤2,4 м/с, сопротивление ≤10 Па, затухание 15–20 дБ(А)
    - Съёмная крышка с прокладкой, HVAC-материал, волокна только за экраном
    - Пересчёт компоновки модуля: вариант А (змейка в две строки)
2026-09-27 Крепёжная карта v3.1 и описание сессии 28.09.2026
    - Три контура крепления, правило «крепёж под отказ», виброопоры с расчётом
    - Узлы зоны выращивания: актуатор света, SBR16 для SCROG, телескопы кассеты
    - Позиции крепежа с ссылками, чек-лист сборки
    - Хронология сессии: анализ архива, создание репо, инженерия v3.1
2026-09-30 CAD v3.1 rev.2: модульная параметрическая модель A/B/C — детали STEP, сборка, DXF раскроя
    [01_Боковина_левая_B-C.dxf, 01_Боковина_левая_B-C.step, 02_Боковина_правая_B-C.dxf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]
2026-09-30 Локальная сборка на ПК: setup.ps1, build.bat, requirements.txt, инструкция в README
2026-09-30 Вариант ОТКРЫТО (двери/ящики/газлифты) + руководство по связям движения в КОМПАС
    [01_Боковина_левая_B-C.dxf, 01_Боковина_левая_B-C.step, 02_Боковина_правая_B-C.dxf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]
2026-09-30 Fix: корпус модуля A (боковины/крышка/задняя), транслит имён STEP вместо кракозябр, names_map.csv
    [01_Bokovina_levaya_B-C.dxf, 01_Bokovina_levaya_B-C.step, 01_Боковина_левая_B-C.dxf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]
2026-09-30 Двустворчатая дверь камеры: две створки (левая/правая) вместо одной, обновлены связи в kompas_motion
    [01_Bokovina_levaya_B-C.dxf, 01_Bokovina_levaya_B-C.step, 02_Bokovina_pravaya_B-C.dxf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]
2026-09-30 Две двери по секциям: левая тех-отсек 434×1700, правая камера роста 814×1700; внутренние фасады ящиков утоплены
    [01_Bokovina_levaya_B-C.dxf, 01_Bokovina_levaya_B-C.step, 02_Bokovina_pravaya_B-C.dxf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]
2026-09-30 Пол и перекрытие по модульно: Дно_B 418×700 + Дно_C 796×700 (шов по перегородке B/C)
    [01_Bokovina_levaya_B-C.dxf, 01_Bokovina_levaya_B-C.step, 02_Bokovina_pravaya_B-C.dxf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]
2026-09-30 Три двери против провисания: B 434 + C1 405 + C2 405, петли ×4, зазоры 3 мм
    [01_Bokovina_levaya_B-C.dxf, 01_Bokovina_levaya_B-C.step, 02_Bokovina_pravaya_B-C.dxf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]
2026-09-30 rev.3: 6 улучшений (3 двери-сэндвич 41мм, цоколь+LED, органайзер, крышки баков, гермовводы) + главный PDF-документ (12 стр.)
    [01_Bokovina_levaya_B-C.dxf, 01_Bokovina_levaya_B-C.step, 02_Bokovina_pravaya_B-C.dxf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]
2026-10-02 Инженерная сессия 03.10: акустика, тепло, электрика, выбор железа
    Новый документ: pdf/growbox_v31_decisions.pdf (12 стр.) — итоги сессии.
    Старый growbox_v31_rev3.pdf не изменён.
    Расчёты:
    - airflow_thermal_calc.py — тракт и тепловой баланс, пересчитывается
    * тракт 104 Па, рабочая точка ~125-135 м3/ч, резерва нет
    * тепло 481 Вт -> +10,6 К при 135 м3/ч; для +5 К нужно 287 м3/ч
    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
2026-10-03 web/: каноническая интерактивная 3D-страница из CAD-геометрии
    - index.html: 85 деталей из build_v31_modular.py, двери/ящики/газлифты на
    реальных петлях (B — x=0, C1 — x=437, C2 — x=1250; газлифты — верхняя кромка)
    - viewer_mobile.html: компактный просмотрщик под телефон
    - model_parts.js: bbox/цвета/тип каждой детали (генерируется из сборки)
    - vendor/three.min.js: three.js r128 UMD — работает офлайн и с file://
2026-10-03 Сайт PIANO + закрытие чек-листа ⑧ + крепёжная карта под модули A/B/C
    - сайт PIANO (6 страниц): index, 3d, modules, engineering, build, gallery + site-assets/site.css
    - 3d.html: улучшенный просмотрщик из CAD-геометрии (85 деталей, режимы, выбор детали)
    - docs/safety_logic_sim.py + отчёт: прогон safety-логики, 13 сценариев, 8 инвариантов
    - models/v3.1/reports/safety_logic.txt: протокол
    - docs/growbox_v3.1_fasteners.md: пересборка под модульную схему A/B/C
    - web/onefile.html + sources/web-prototypes/: однофа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
